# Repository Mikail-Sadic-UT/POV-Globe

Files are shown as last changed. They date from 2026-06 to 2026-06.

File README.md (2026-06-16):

# POV Globe

A persistence-of-vision LED globe. A blade carrying a strip of SK9822 LEDs spins on a brushless motor; image columns are clocked out in sync with the motor's hall sensor so a stable spherical image hangs in mid-air.

---

## How It Works

A hall sensor feeds back the motor's rotation period. A timer divides that period across the number of angular columns and fires at that rate — each tick, the next column of image data is pushed out to the LEDs via DMA while the CPU stays free.

Three display modes:

| Mode | Description |
|---|---|
| Static image | Indexed image loaded from ROM or SD card |
| Animation | GIF streamed from SD card, double-buffered per rotation |
| Mic / VU meter | Electret mic drives a colour bar from hub to tip |

---

## Repository Layout

```
POV-Globe/
├── Firmware/     Code Composer Studio project (TM4C123GH6PM)
├── Hardware/     KiCad 9.0 PCB files
├── Mechanical/   Step files
├── Scripts/      Python image conversion tools
└── BOM.xlsx      Bill of materials
```

---

## Firmware

Targets the TI TM4C123GH6PM (Tiva C) using [Code Composer Studio](https://www.ti.com/tool/CCSTUDIO).

### Quick Start

1. Open the project in Code Composer Studio (`Firmware/src/`).
2. Make sure `main_sd.c` is the active entry point.
3. Connect the board and hit **Debug** — CCS flashes and starts execution.
4. Use the LCD buttons to navigate the menu, select content, and control the motor.

### Adding Content

**ROM image** (compiled into flash, no SD card needed):

```bash
cd Scripts
python globe_convert.py myimage.png
```

Move the output into `Firmware/src/Data/myimage/` and register the entry in `main_sd.c`. See [`Scripts/Documentation.md`](Scripts/Documentation.md) for details.

**SD card animation** (streamed at runtime):

```bash
python globe_convert_gif.py myanim.gif
```

Copy the `.bin` file to the SD card and register the palette entry in `main_sd.c`. See [`Scripts/Documentation.md`](Scripts/Documentation.md) for details.

### Docs

Detailed module documentation lives in `Firmware/src/Documentation/`:

- [`main_sd.md`](Firmware/src/Documentation/main_sd.md) — application architecture, display modes, init order
- [`Motor.md`](Firmware/src/Documentation/Motor.md) — PWM control, hall RPM capture, ramp state machine
- [`SK9822.md`](Firmware/src/Documentation/SK9822.md) — frame builders and wire format
- [`SSI-DMA.md`](Firmware/src/Documentation/SSI-DMA.md) — DMA pipeline and SPI setup

---

## Hardware

KiCad 9.0 is required to open the schematic and PCB files. All design files and documentation are inside the `Hardware/` folder.

---

## Scripts

| Script | Purpose |
|---|---|
| `globe_convert.py` | Converts an equirectangular image to C arrays for ROM or SD use |
| `globe_convert_gif.py` | Converts a GIF to a binary + palette for SD card streaming |
| `toBin.py` | Binary packing utility |

See [`Scripts/Documentation.md`](Scripts/Documentation.md) for full usage.

## Mechanical

See Mechanical Folder for STEP models and assembly. 
Youtube video:

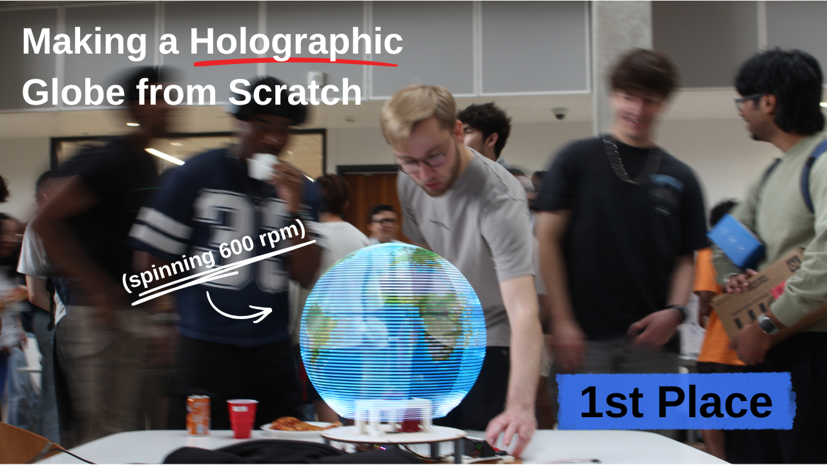
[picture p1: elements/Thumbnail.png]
Demo Video (https://youtu.be/JPuDUcfGZ3w)


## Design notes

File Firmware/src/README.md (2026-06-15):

# POV LED Globe — TM4C123 Driver

A persistence-of-vision LED globe powered by a TM4C123GH6PM. A 143-LED SK9822 strip is mounted on a spinning blade; columns of image data are clocked out at a rate locked to the motor's hall-sensor feedback so a stable image fuses in mid-air.

Supports static images (ROM and SD card), animated GIFs streamed from SD, and a microphone-driven VU meter.

---

## Hardware

| Component | Part | Interface |
|---|---|---|
| MCU | TI TM4C123GH6PM (Tiva C) | 80 MHz |
| LEDs | 143× SK9822 (originally 144) | SSI2 + uDMA, 20 MHz |
| Motor | TEC3650 BLDC + 6:1 gearbox | PWM + hall capture |
| LCD | ST7735 128×160 colour TFT | SSI0 |
| SD card | FAT32 SD/SDHC | SSI0 (shared bus) |
| Microphone | Analog electret | ADC0 / AIN0 |

---

## Pin Map

```
PORT A — LCD + SD card (SSI0)
  PA2  SSI0 SCLK    → ST7735 SCK / SD card SCK
  PA3  SSI0 FSS     → ST7735 CS
  PA4  SSI0 RX      → SD card MISO
  PA5  SSI0 TX      → ST7735 MOSI / SD card MOSI
  PA6  GPIO out     → ST7735 D/C
  PA7  GPIO out     → ST7735 RESET

PORT B — LEDs (SSI2) + LCD buttons
  PB1  GPIO in      → LCD button "Up"
  PB2  GPIO in      → LCD button "Down"
  PB3  GPIO in      → LCD button "Select"
  PB4  SSI2 SCLK    → SK9822 CLK
  PB7  SSI2 TX      → SK9822 DI

PORT C — Motor
  PC4  WT0CCP0      → hall sensor (open-drain, falling edge)
  PC5  M0PWM7       → motor PWM (active-low, 20 kHz)
  PC6  GPIO out     → direction (0 = forward)

PORT E — Microphone
  PE3  AIN0         → mic analog input

PORT F — Motor buttons + RGB heartbeat LED
  PF0  GPIO in      → motor spin-up
  PF1  GPIO out     → red LED
  PF2  GPIO out     → blue LED
  PF3  GPIO out     → green LED
  PF4  GPIO in      → motor spin-down

SD card chip-select: dedicated GPIO (see diskio_DMA.c)
```

---

## Repository Layout

```
.
├── main.c                  Stripped-down version, ROM-only (no SD card)
├── main_sd.c               Full application, the one you'll use
├── main.h
│
├── Drivers/
│   ├── inc/                Driver headers
│   └── src/                Driver source
│       ├── SK9822.c              Frame builders (image → SPI bytes)
│       ├── SK9822_DMA_SSI.c      DMA pipeline (SPI bytes → LEDs)
│       ├── Motor.c               PWM + hall RPM + ramp state machine
│       ├── LCD.c                 ST7735 menu UI
│       ├── GPIO.c                Port B/F button ISRs + heartbeat LED
│       ├── Mic.c                 ADC0 single-sample reader
│       ├── DMA_Common.c          uDMA controller init
│       ├── SD_DMA.c              SD card SPI-RX via uDMA
│       ├── diskio_DMA.c          FatFs disk I/O backend
│       ├── ff.c                  FatFs filesystem (3rd party)
│       ├── ST7735.c              LCD low-level driver (3rd party)
│       ├── Timer*A.c             32-bit periodic timer wrappers
│       └── Unified_Port_Init.c   GPIO bring-up boilerplate
│
├── Data/                   Image and animation data
│   ├── map_*.{c,h}              Earth (ROM, 8-bit)
│   ├── dermot/, vote/, eye/     Other ROM 8-bit images
│   ├── cat_space/, frog/, ...   Animation palettes (data on SD as .bin)
│   └── globe_old/               Legacy 144-LED data, kept for reference
│
├── Tests/                  Standalone test programs
│   ├── DMA_test.c               Exercise SK9822 DMA pipeline alone
│   ├── Motor_test.c             Sweep motor 0%-100% in both directions
│   ├── SD_Card.c                SD card read smoke test
│   ├── SD_Card_Sanity_Check.c   FatFs read/write verification
│   └── SD_Card_Write.c          (unused) write image data to SD
│
├── Documentation/          Module-level docs
│   ├── SSI-DMA.md               LED DMA pipeline deep-dive
│   ├── SK9822.md                Frame builder reference
│   ├── Motor.md                 Motor driver internals
│   └── main_sd.md               Application architecture
│
└── Debug/                  Build artefacts (gitignored)
```

---

## Quick Start

1. Open the project in **Code Composer Studio**.
2. Make sure the build is targeting `main_sd.c` (not `main.c` or any of the test programs — only one `main` can be active at a time).
3. Connect the board, hit **Debug**. CCS auto-flashes and starts execution.
4. The LCD shows the menu. Use PB1/PB2/PB3 to navigate.
5. PF0 spins the motor up, PF4 spins it down (also accessible from the LCD menu).

### Switching what gets built

Each `main*.c` defines a different `main()` entry point. To change which one runs, edit the file you don't want to use so its entry point is named something other than `main` (e.g. `main2`, `main88`). Only the file containing the actual `main` will be the program entry.

---

## How It Works

The motor spins a blade carrying a strip of LEDs. A hall sensor tells us the rotation period. We divide that period by the number of angular columns we want, and use that as the firing rate for the hardware Timer. Each Timer tick, the next column of pre-computed image data is expanded to the SPI wire format and shifted out via **DMA + SSI2** — fast enough that the LEDs change colour many times per revolution, painting an image in space. The CPU is mostly idle during all this, free to handle the LCD menu, motor ramp, and SD card streaming.

For a thorough walkthrough see [Documentation/main_sd.md](Documentation/main_sd.md).

---

## Adding New Content

### New ROM image (compiled into flash)

```
python globe_convert.py myimage.png --mode 8bit
mkdir Data/myimage
mv myimage_data.{c,h} myimage_palette.{c,h}  Data/myimage/
```

Then in `main_sd.c`:

```c
#include "Data/myimage/myimage_data.h"
#include "Data/myimage/myimage_palette.h"

static const ContentEntry_t pictures[] = {
    /* ...existing entries... */
    { "MyImage", CONTENT_ROM_8BIT, myimage_data, myimage_palette,
      GLOBE_NUM_COLUMNS, NULL },
};
```

### New animation (streamed from SD)

```
python globe_convert_gif.py myanim.gif --mode 4bit
cp myanim.bin /path/to/sd/  →  rename to 8.3 format, e.g. mya.bin
mkdir Data/myanim
mv myanim_palette.{c,h}  Data/myanim/
```

Then in `main_sd.c`:

```c
#include "Data/myanim/myanim_palette.h"

static const ContentEntry_t animations[] = {
    /* ...existing entries... */
    { "MyAnim", CONTENT_SD_4BIT_ANIM, NULL, myanim_palette, 0, "mya.bin" },
};
```

The data file goes on the SD card; the palette is small enough to live in flash.

---

## Compile-Time Toggles

In `main_sd.c`:

| Macro | Default | Effect |
|---|---|---|
| `HALL_SYNC` / `FIXED_TIMER` | `HALL_SYNC` | Column rate locked to motor RPM, or fixed at `FIXED_PERIOD` |
| `ISR_BUILD_ON_DMA_DONE` / `ISR_BUILD_IN_TIMER` | `ISR_BUILD_ON_DMA_DONE` | Where `BuildFrame()` runs |
| `FIXED_PERIOD` | `152000` | Initial / fallback Timer4A reload (80 MHz ticks) |
| `brightness` | `16` | Global LED brightness 0–31 (variable, not macro) |

In `Drivers/inc/Motor.h`:

| Macro | Default | Effect |
|---|---|---|
| `MOTOR_SETPOINT` | `67` | Default duty% the spin-up button targets |
| `MIN_STARTSPEED` | `20` | Minimum duty% needed to overcome friction |
| `MAX_SPEED` | `90` | Hard ceiling for `Motor_SetSpeed()` |
| `MOTOR_SPINUP_MS` | `250` | ms per 1% step on spin-up |
| `MOTOR_SPINDOWN_MS` | `100` | ms per 1% step on spin-down |

---

## Interrupt Priority Map

| IRQ | Source | Priority | Notes |
|-----|---|---|---|
| 94  | Wide Timer 0A (hall) | **1** | missed edge = wrong RPM = drift|
| 57  | SSI2 (LED DMA done) | 2 | Triggers next frame build |
| — | SysTick (1 ms) | 2 | Motor ramp, stall check |
| 70  | Timer4A (column clock) | 3 | Fires `LEEEED()` |
| 92  | Timer5A (FatFs disk timer) | 4 | SD card timeouts |
| 1 | Port B (LCD buttons) | 5 | Human input |
| 30  | Port F (motor buttons) | 5 | Human input |

---

## Memory Footprint

```
SRAM (32 KB total):
  sdMem (image union)              ~20 KB
  DMA_FRAME + BUF_FRAME             1.2 KB
  stack, ISR vars, FatFs state    ~ 1.5 KB
  free                            ~ 9 KB

Flash:
  application code                  ~25 KB
  ROM image data                    ~20 KB per 8-bit image
  ROM palette data                   768 B per 8-bit, 48 B per 4-bit
  FatFs                             ~10 KB
```

ROM image data dominates flash usage. Each additional 8-bit image adds 140 × 143 = 20,020 bytes.

---

## Documentation

For deeper dives into specific subsystems:

- [Documentation/main_sd.md](Documentation/main_sd.md) — application architecture, mode switching, content table, init order
- [Documentation/Motor.md](Documentation/Motor.md) — PWM control, hall capture ISR, RPM math, ramp state machine
- [Documentation/SK9822.md](Documentation/SK9822.md) — frame builders, wire format, compressed formats
- [Documentation/SSI-DMA.md](Documentation/SSI-DMA.md) — LED DMA pipeline, ping-pong descriptors, SSI2 init

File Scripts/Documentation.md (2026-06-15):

# globe_convert.py

Converts an equirectangular image into C arrays ready for use on the TM4C123 POV globe driver.

---

## Usage

```bash
python globe_convert.py <image>
```

**Example:**
```bash
python globe_convert.py world_map.png
```

All tuning parameters are configured inside the script — no command-line flags needed.

---

## Configuration

Edit the `CONFIG` block at the top of the script before running:

```python
NUM_COLUMNS   = 140     # Angular slices per 180° blade sweep <-- Should be theoretical limit
NUM_LEDS      = 144     # Total LEDs on the blade
FRONT_LEDS    = 72      # LEDs on the front face
PALETTE_SIZE  = 256     # Colours in the 8-bit palette (max 256)
OUTPUT_DIR    = "."     # Directory to write generated files into
```

| Parameter | Description |
|---|---|
| `NUM_COLUMNS` | Angular resolution — number of image slices per half rotation. 140 gives ~1.28° per step at 900 RPM. |
| `NUM_LEDS` | Total LEDs on the blade. Must match `NUM_LEDS` in `SK9822.h`. |
| `FRONT_LEDS` | How many LEDs are on the front face. Remaining LEDs are the back face. |
| `PALETTE_SIZE` | Number of colours in the palette. 256 = 8-bit. Reducing to 16 enables 4-bit mode. |
| `OUTPUT_DIR` | Where the four output files are written. Created if it doesn't exist. |

---

## Input Image

The script for now expects an **equirectangular projection** image (but will work with whatever):

- **X axis** → angular position (0–360°, left to right)
- **Y axis** → radial position (hub at top, tip at bottom)

The image is automatically resized to `(NUM_COLUMNS × 2) × NUM_LEDS` pixels internally, so any input resolution works.

Standard equirectangular images (world maps, 360° photos) work directly. If the image is not equirectangular it will produce distorted output. Will probably have to make another script to do this, or figure something out for general photos.

---

## Globe Geometry

The blade has 144 LEDs arranged radially from hub to tip:

```
Hub                                       Tip                                      Hub
 |-------- Front face (LED 0–71) ----------|-------- Back face (LED 72–143) --------|
```

- **Front face** (LED 0–71): sampled hub→tip from the column angle
- **Back face** (LED 72–143): sampled tip→hub from column angle + 180°, stored in reverse radial order so LED 72 sits at the tip adjacent to LED 71

This means the image is seamless across the physical blade centre — the pixel at LED 71 (front tip) and LED 72 (back tip) are adjacent in the source image.

A full rotation is reconstructed from two blade passes:

```
Pass 1 (0°–180°):   columns 0–139   →  front face = 0°–180°,  back face = 180°–360°
Pass 2 (180°–360°): same columns    →  front face = 180°–360°, back face = 0°–180°
```

---

## Processing Pipeline

```
Load image
    │
    ▼
Resize to (NUM_COLUMNS×2) × NUM_LEDS
    │
    ▼
K-means clustering (256 colours)  ←  builds optimal palette for this image
    │
    ▼
Quantize pixels → palette indices
    │
    ▼
Sample globe columns
    │   for each column: sample front strip at angle,
    │                    sample back strip at angle + 180°
    ▼
Write C files
```

### Palette generation

The palette is built using **MiniBatchKMeans clustering** — it finds the 256 colours that best represent the full colour distribution of the image. This is strictly better than a fixed 3-3-2 mapping because the 256 entries are chosen specifically for your image rather than being uniformly distributed.

### Quantization

Each pixel is mapped to its nearest palette entry using squared Euclidean distance in RGB space. Processed in chunks of 4096 pixels to avoid memory issues on large images.

---

## Output Files

Four files are generated in `OUTPUT_DIR`:

| File | Contents | Size |
|---|---|---|
| `palette.h` | `extern` declaration, `PALETTE_SIZE` define | — |
| `palette.c` | `const uint8_t palette[256][3]` — RGB entries | 768 bytes |
| `globe_data.h` | `extern` declaration, `GLOBE_NUM_COLUMNS` / `GLOBE_NUM_LEDS` defines | — |
| `globe_data.c` | `const uint8_t globe[140][144]` — palette indices | 20,160 bytes |

**Total: ~20,928 bytes (~20.4 KB)** — fits in TM4C123 32 KB SRAM with ~11.6 KB spare.

> Set as `const` to place them in flash (256 KB) instead of SRAM, freeing SRAM for frame buffers and stack.

---

## MCU Integration

Add the four generated files to your project under `Data/`:

```
Data/
  palette.h
  palette.c
  globe_data.h
  globe_data.c
```

Include in your main file and call `BuildFrame_8bit` with the current column:

```c
#include "../Data/globe_data.h"
#include "../Data/palette.h"

uint16_t col        = 0;
uint8_t  brightness = 2;   // 0-31

// In main loop:
if(framePending){
    BuildFrame_8bit(BUFF, globe[col], palette, brightness);
    col = (col + 1) % GLOBE_NUM_COLUMNS;
    frameDirty  = 1;
    framePending = 0;
}
```

`BuildFrame_8bit` expands the 144 palette indices for column `col` into the full 596-byte SK9822 wire format (start frame + BGR LED frames + end frame) and writes it into `BUFF`.

---

## Dependencies

```bash
pip install pillow numpy scikit-learn
```

| Package | Use |
|---|---|
| `Pillow` | Image loading and resizing |
| `numpy` | Array operations and vectorised quantization |
| `scikit-learn` | `MiniBatchKMeans` for palette generation |

---

## Notes

- **One palette per image** — the palette is optimised for the specific input image. If you load multiple images on the globe, each needs its own palette, or you can generate a shared palette by running k-means across all images combined.
- **Equirectangular only** — other projections (Mercator, stereographic, etc.) will produce distorted output without a pre-conversion step.
- **Brightness** — the `brightness` parameter (0–31) is the SK9822 global brightness field, separate from pixel colour values. Stay low (1–3) because this shit is bright af.

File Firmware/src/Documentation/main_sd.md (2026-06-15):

# main_sd.c — POV Globe Application

## Overview

The application layer for the POV LED globe. Coordinates four subsystems:

- **Frame builders** ([SK9822.md](SK9822.md)) — turn images into SPI byte streams
- **DMA driver** ([SSI-DMA.md](SSI-DMA.md)) — shifts frames out to the LEDs
- **Motor driver** ([Motor.md](Motor.md)) — keeps the blade spinning, provides hall feedback
- **LCD menu** — user input for mode/content selection

```
┌─────────────────┐
│  LCD menu       │ ── selects ───▶ Globe_ToggleMode / Globe_ChangeContent
│  (LCD.c)        │
└─────────────────┘
                                            │
                                            ▼
┌─────────────────┐         ┌────────────────────────────────┐
│  Motor (hall)   │ ──RPM──>│  Timer4A ISR  (HALL_SYNC mode) │
└─────────────────┘         │     ↓                          │
                            │  LEEEED() ──> LoadDMA()        │
                            │                  ↓             │
                            │   SSI2_Handler ──> BuildFrame()│
                            │     (DMA done)                 │
                            └────────────────────────────────┘
                                            │
                                            ▼
                            ┌────────────────────────────────┐
                            │  Mic / SD / ROM / palette LUT  │
                            └────────────────────────────────┘
```

---

## Display Modes

```c
typedef enum {
    MODE_8BIT_STATIC,   // single 8-bit image, ROM or SD
    MODE_4BIT_ANIM,     // 4-bit animation from SD, double-buffered
    MODE_MIC            // VU meter from PE3 ADC
} DisplayMode_t;
```

Three sources of image data feed the same DMA pipeline:

| Mode | Data source | Per-column behaviour |
|---|---|---|
| `MODE_8BIT_STATIC` + `SRC_ROM` | flash array (`romData[col]`) | palette lookup |
| `MODE_8BIT_STATIC` + `SRC_SD`  | RAM (`sdMem.static8[col]`) | palette lookup |
| `MODE_4BIT_ANIM` | RAM (`sdActive[col]`) | palette lookup, swap buffers at col=0 |
| `MODE_MIC` | ADC sample | `BuildFrame_VU()` |

---

## Memory Budget

The TM4C123 has 32 KB of SRAM. The largest user is the SD/animation buffer pool, which uses a **union** to overlay 8-bit and 4-bit layouts on the same memory:

```c
static union {
    uint8_t static8[140][143];          // 20,020 B — 8-bit static
    struct {
        uint8_t a[140][72];             // 10,080 B — 4-bit buffer A
        uint8_t b[140][72];             // 10,080 B — 4-bit buffer B
    } anim4;
} sdMem;                                // 20,160 B total
```

In addition:

```
DMA_FRAME, BUF_FRAME (double SPI buffer)  =  2 × 592   = 1,184 B
sdMem (union)                             ≈            = 20,160 B
ROM image data (in flash, not SRAM)
Misc state                                ≈            = ~500 B
                                                         ───────
                                                        ~22 KB used
```

Adding more pictures or animations costs **flash** (palette + index data),
not SRAM, since `pictures[]` and `animations[]` are `const`.

---

## Double-Buffering Strategy

Two layers of double-buffering, used at different time scales:

### 1. SPI wire buffers (per column)

```
LIVE  →  being shifted out by DMA
BUFF  →  being filled by BuildFrame_xxx()

After DMA completes:
   swap(LIVE, BUFF)
   restart DMA on new LIVE
   build next column into new BUFF
```

This is what `LoadDMA()` does — it checks `dmaBusy`, swaps pointers if a new column is ready (`frameDirty`), and kicks the next transfer.

### 2. Animation frame buffers (per rotation)

```
sdActive  →  140 columns being read by BuildFrame_4bit
sdLoading →  next animation frame, loaded from SD in main loop

When col == 0 (rotation boundary) and sdReady:
   swap(sdActive, sdLoading)
   sdReady = 0
```

The swap only happens at the rotation boundary so the user never sees a torn frame mid-rotation. The main loop watches `sdReady` and starts loading the next frame as soon as the previous one is consumed.

---

## ISR Architecture

Two compile-time options control where work happens (see toggles in main_sd.c):

### `ISR_BUILD_IN_TIMER`
Both `LoadDMA()` and `BuildFrame()` run in the Timer4A ISR.

```
Timer4A tick:
   ├── HallSync_UpdatePeriod()    // ~3 µs
   ├── LoadDMA()                  // ~2 µs
   └── BuildFrame()               // ~10 µs
                                  total ~15 µs ISR
```

Simple. Fine up to ~50 kHz column rate.

### `ISR_BUILD_ON_DMA_DONE`  (current default)

Timer4A only kicks DMA. Frame building runs from `SSI2_Handler` after the SPI transfer completes.

```
Timer4A tick:                    SSI2 DMA-done (~30 µs after timer):
   ├── HallSync_UpdatePeriod()      └── DMA_Done_Callback()
   └── LoadDMA()                          └── BuildFrame()
       (~5 µs ISR)                              (~10 µs ISR)
```

CPU isn't blocked during the SPI transfer — `BuildFrame()` runs in parallel with SPI shifting. Better for high column rates.

`DMA_Done_Callback()` is called from `SSI2_Handler` (in SK9822_DMA_SSI.c).

---

## Timing: Fixed vs Hall-Sync

```
#define HALL_SYNC      // (current default)
// #define FIXED_TIMER
```

### `FIXED_TIMER`
Timer4A fires at a constant period (`FIXED_PERIOD = 152000` ticks at 80 MHz, ≈526 Hz). Image position drifts as motor RPM varies. (Only as accurate as what you are reading directly from the motor, and slipage down the line will cause image drift)

### `HALL_SYNC`
Every Timer4A tick, the period is recomputed from the most recent measured motor revolution:

```
colPeriod = revPeriod × MOTOR_GEAR_RATIO / SD_NUM_COLUMNS
          = revPeriod × 6 / 140
```

Image stays locked to physical position even if motor RPM drifts. Until the first revolution is measured, falls back to `FIXED_PERIOD`.

The clamps `5000 ≤ colPeriod ≤ 400000` bound the column rate to roughly **200 Hz – 16 kHz**, avoids silly values and nothing happening when motor off.

---

## Content Table

`pictures[]` and `animations[]` register all selectable content. Each entry is a `ContentEntry_t`:

```c
typedef struct {
    const char       *name;
    ContentType_t     type;          // ROM_8BIT / SD_8BIT / SD_4BIT_ANIM
    const uint8_t   (*romData)[NUM_LEDS];
    const uint8_t   (*palette)[3];
    uint16_t          romCols;
    const char       *sdFilename;
} ContentEntry_t;
```

### Adding new content

**ROM-resident image** (compiled into flash, no SD card needed):

1. Run `globe_convert.py` on your image
2. Copy the generated `*_data.h/c` and `*_palette.h/c` into `Data/myImage/`
3. `#include` the headers in main_sd.c
4. Add an entry to `pictures[]`:
   ```c
   { "MyImage", CONTENT_ROM_8BIT, my_data, my_palette, GLOBE_NUM_COLUMNS, NULL },
   ```

**SD card animation** (4-bit GIF, no flash cost):

1. Convert the GIF: `python globe_convert_gif.py myAnim.gif --mode 4bit`
2. Copy the resulting `myAnim.bin` to the SD card
3. `#include` the palette header (palette still goes in flash)
4. Add an entry to `animations[]`:
   ```c
   { "MyAnim", CONTENT_SD_4BIT_ANIM, NULL, my_palette, 0, "mya.bin" },
   ```

The SD filename is limited to 8.3 characters by FatFs in default config.

---

## LCD Menu Integration

The LED menu in `LCD.c` calls into main_sd.c through two extern functions:

```c
void Globe_ToggleMode(void);    // cycles picture → animation → mic → picture
void Globe_ChangeContent(void); // cycles within current category
```

`ledModeAnim` is shared between the two files (defined in LCD.c, read here):

| Value | Meaning |
|---|---|
| 0 | Picture mode |
| 1 | Animation mode |
| 2 | Mic mode |

LCD.c handles the button input and screen rendering. main_sd.c handles the actual mode switching and content loading.

---

## Mic Mode Detail

```c
if (displayMode == MODE_MIC) {
    raw = Mic_Read();
    uint16_t level = ((raw * FRONT_LEDS) / 4096) - 33;
    BuildFrame_VU(BUFF, level, brightness);
}
```

`Mic_Read()` triggers ADC0 sequencer 3 (single sample on PE3/AIN0) and polls for completion. Returns 0–4095.

Scaling to LED count:
```
level = raw × 71 / 4096 - 33
```

The `-33` offset trims out ambient ADC bias so the bar sits near zero in silence. Tune per microphone.

`BuildFrame_VU()` ([SK9822.md](SK9822.md)) draws a green→yellow→red bar from hub to tip on both faces.

The mic is sampled once per column (~500 Hz with default timing). The current code shows the *instantaneous* sample.

---

## Initialisation Sequence

`INITIALIZE()` brings up subsystems in dependency order:

```
1. PLL_Init(80MHz)               clock first — everything else needs it
2. SK9822_20MHZ()                SSI2 + GPIO PB4/PB7
3. DMA_Init()                    uDMA controller
4. SK9822_DMA_CH13_Init()        LED DMA channel
5. SD_DMA_CH10_Init()            SD card DMA channel
6. Motor_Init()                  PWM + hall capture
7. Motor_Stop()                  ensure motor is off
8. PF_Init() / PB_Init()         button GPIO + IRQs
9. SysTick_Init(1ms)             tick + ramp + stall check
10. Mic_Init()                   ADC0 seq3
11. BuildFrame_Solid(LIVE/BUFF)  clear LED buffers
12. LCD_Menu_Init()              ST7735 + initial render
```

`Timer4A_Init()` is called from `main()` after `SetMode_ROM()` loads the first picture, so the ISR doesn't fire on uninitialised data.

---

## Main Loop

```c
while (1) {
    if (displayMode == MODE_4BIT_ANIM && !sdReady)
        SD_LoadNextFrame();          // SD I/O happens here, not in ISR

    buttonHandler();                  // consume LCD button flags

    if (motor_state_changed) {
        // redraw motor status indicator on LCD
    }
}
```

All slow / blocking operations (SD card reads, LCD redraws) happen here so the ISRs stay short.

---

## Compile-time Toggles Summary

| Toggle | Default | Effect |
|---|---|---|
| `HALL_SYNC` / `FIXED_TIMER` | `HALL_SYNC` | Column rate locked to motor or fixed |
| `ISR_BUILD_ON_DMA_DONE` / `ISR_BUILD_IN_TIMER` | `ISR_BUILD_ON_DMA_DONE` | Where BuildFrame runs |
| `FIXED_PERIOD` | `152000` | Initial / fallback Timer4A period |
| `brightness` (variable) | `16` | Global LED brightness, 0–31 |

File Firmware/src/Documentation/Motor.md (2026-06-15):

# BL2430 Motor Driver

## Overview

Drives a TEC3650 brushless DC motor through a 6:1 reduction gearbox.
Provides three things:

1. **PWM speed control** with non-blocking spin-up / spin-down ramps
2. **Direction control** via a digital pin
3. **Live RPM measurement** from the hall-effect sensor

The motor sits on Port C:

| Pin | Function | Direction | Notes |
|-----|---|---|---|
| PC4 | WT0CCP0  | input  | Hall sensor, falling-edge capture |
| PC5 | M0PWM7 | output | Active-low PWM, 20 kHz |
| PC6 | GPIO | output | Direction (0 = forward) |

---

## PWM Speed Control

PWM uses **PWM Module 0, Generator 3, output B** (M0PWM7 on PC5). The signal is **active-low**: the line idles high (motor off) and pulses low for the active fraction of each period.

```
Period = 80 MHz / 20 kHz = 4000 counts
Duty   = CMPB / LOAD
```

Three special cases short-circuit the normal counter:
- **0%** → GENB forced constant high (motor off)
- **100%** → GENB forced constant low (full speed)
- **1–99%** → normal count-down PWM

### Rate Limiter

`Motor_SetSpeed()` rejects single-call jumps larger than `MAX_STEP` (25%). This protects the driver and motor from sudden current spikes. To change speed by more than 25%, use `Motor_Spinup()` / `Motor_Spindown()` which ramp gradually.

---

## Spin-Up / Spin-Down Ramps

Both functions are **non-blocking** — they store the target state and return. `Motor_Tick()` (called from SysTick at 1 ms) advances the ramp by one step every `motorStepDelay` ms.

```
MOTOR_IDLE
    │
    │  Motor_Spinup(250, 67)
    ▼
MOTOR_SPINNING_UP  ──── increment 1%/250ms ──── reaches target ──▶ MOTOR_IDLE
    │
    │  Motor_Spindown(100)  [preempts spinup]
    ▼
MOTOR_SPINNING_DOWN ── decrement 1%/100ms ──── reaches 5% ──▶ Motor_Stop() ──▶ MOTOR_IDLE
```

Spin-down always preempts spin-up. Spin-up is ignored if a spin-down is already running.

The spin-down ramp stops at 5% rather than 0% and calls `Motor_Stop()` directly — at very low duty cycles the motor behaviour is unpredictable, so it's safer to cut PWM cleanly than to creep down to zero.

### State variables (all volatile)

| Variable | Owner | Purpose |
|---|---|---|
| `motorRampState` | Motor_Tick / Spinup / Spindown | Current ramp phase |
| `motorCurSpeed` | Motor_Tick | Most recently applied duty% |
| `motorTargetSpeed` | Motor_Spinup | Spin-up destination |
| `motorStepDelay` | Spinup / Spindown | ms between 1% steps |
| `motorLastTick` | Motor_Tick | msTick when last step ran |
| `motor_state_changed` | all writers | Flag for main loop to redraw LCD |

---

## Hall Sensor RPM Capture

PC4 receives the hall sensor's open-drain output. We use **Wide Timer 0A in capture mode** — every falling edge latches the timer's current value, generating an interrupt.

The TEC3650 produces **12 hall pulses per motor revolution** (4 pole pairs × 3 phases). One full motor revolution = 12 captured edges.

### ISR Flow (`WideTimer0A_Handler`)

```
edge fires
    │
    ▼
read WTIMER0_TAR_R (latched timestamp)
    │
    ▼
delta = wtPrev - now    (timer counts down from 0xFFFFFFFF)
    │
    ▼
glitch reject: delta < 0.6 × lastValidDelta?  ──▶ ignore
    │
    ▼
stall check: delta > STALL_DELTA (1 sec)?     ──▶ motorRPM = 0, reset
    │
    ▼
update gearPulseCount (mod GEAR_PPR=54)
accumulate wtDeltaSum, increment wtPulse
    │
    ▼
wtPulse == 12?                                ──▶ compute motorRPM,
                                                  save lastRevPeriod,
                                                  reset accumulator
```

### RPM Math

```
RPM = (SYS_CLK × 60) / (HALL_PPR × delta_per_pulse)
    = RPM_SCALE_REV / wtDeltaSum

where RPM_SCALE_REV = 80,000,000 × 60 = 4,800,000,000
and wtDeltaSum = sum of 12 inter-pulse intervals (one full rev)
```

Computing once per revolution rather than per pulse averages out timing jitter and avoids divisions on every interrupt.

### Glitch Rejection

The hall sensor is open-drain with a pull-up. Without a series resistor on the line, fast slew rates can produce double-pulses near the threshold. The ISR rejects any delta less than 60% of the last valid interval, which discards these glitches without affecting legitimate speed changes (motor accel/decel happens on a much slower timescale).

### Stall Detection

`Motor_StallCheck()` is called from SysTick every 1 ms. It reads the **live** timer value (`WTIMER0_TAV_R`) — not the latched capture register — to measure time since the last edge. If more than 1 second has passed, it forces RPM to 0 and resets the capture state. This handles the case where the motor stops without producing a final edge.

---

## Hall-Sync API (for POV column timing)

The POV globe needs columns delivered at a rate that matches the physical rotation. Two getters expose the hall capture state to `main_sd.c`:

| Function | Returns |
|---|---|
| `Motor_GetRevPeriod()` | 80 MHz tick count for one full motor revolution. 0 = no measurement yet. |
| `Motor_GetGearPulseCount()` | Current position within one gear rev, [0, 54). |
| `Motor_GetGearAngle()` | Same, but in degrees [0, 360). |

In `main_sd.c`, `HallSync_UpdatePeriod()` reads `Motor_GetRevPeriod()` and computes the column timer period:

```
colPeriod = revPeriod × MOTOR_GEAR_RATIO / SD_NUM_COLUMNS
          = revPeriod × 6 / 140
```

This locks the column rate to actual motor speed — the image stays stable even if RPM drifts. (Only factoring Motor drift, any mechanical drifting down the line, ie gear/belt slippage will not be caught)

---

## Public API Summary

```c
void     Motor_Init(void);
uint8_t  Motor_SetSpeed(int8_t percent);     // rate-limited
uint8_t  Motor_SetDirection(uint8_t dir);    // only when stopped
uint8_t  Motor_Stop(void);
void     Motor_Spinup(uint32_t msPerStep, uint8_t targetDuty);
void     Motor_Spindown(uint32_t msPerStep);
void     Motor_Tick(void);                   // call from SysTick
void     Motor_StallCheck(void);             // call from SysTick

uint32_t Motor_GetRPM(void);                 // motor RPM
uint32_t Motor_GetGearRPM(void);             // = motorRPM / 6
uint8_t  Motor_GetDuty(void);                // current duty %

uint32_t Motor_GetRevPeriod(void);           // for hall-sync
uint8_t  Motor_GetGearPulseCount(void);
uint16_t Motor_GetGearAngle(void);
```

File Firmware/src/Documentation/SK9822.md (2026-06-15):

# SK9822 Frame Builders

## Overview

`SK9822.c` provides functions that **build complete SPI frames** in the SK9822 wire format. The DMA driver (`SK9822_DMA_SSI.c`) shifts these frames out — see [SSI-DMA.md](SSI-DMA.md) for that side.

Every builder writes the same buffer layout:

```
┌─────────────┬───────────────────────────┬─────────────┐
│ START_BYTES │  NUM_LEDS × 4 bytes       │  END_BYTES  │
│  4 × 0x00   │  per LED:                 │  16 × 0xFF  │
│             │  [global][B][G][R]        │             │
└─────────────┴───────────────────────────┴─────────────┘
```

Total `FRAMESIZE` = **592 bytes** (4 + 143×4 + 16, supposed to be 144 but one led broke).

---

## SK9822 Wire Format

### Per-LED frame (4 bytes)

```
byte 0:  111 b b b b b     (top 3 bits = 0xE0, bottom 5 = brightness 0-31)
byte 1:  blue
byte 2:  green
byte 3:  red
```

The "global" brightness field is a 5-bit current scaler applied by the LED controller before its 8-bit PWM. Setting global = 0 turns the LED off without sending all-zero RGB, which is a useful distinction when chaining frames.

`START_BITS = 0xE0` is OR'd with the 5-bit brightness to produce the global byte. The driver passes `0xE0` (i.e. global = 0) as the global value for "off" pixels, and `START_BITS | brightness` for lit pixels.

### Wire order

The SK9822 datasheet specifies **BGR order** for the colour bytes, even though every builder accepts RGB inputs. The `WRITE_LED` macro reorders them on output:

```c
#define WRITE_LED(frame, idx, global, r, g, b) \
    do { (frame)[(idx)++] = (global);          \
         (frame)[(idx)++] = (b);               \
         (frame)[(idx)++] = (g);               \
         (frame)[(idx)++] = (r); } while(0)
```

Callers always pass natural `(r, g, b)`. The macro is the single point that knows about the wire order.

### Start and End

The 4-byte all-zero start is a synchronization marker — the SK9822 sees four 0x00 bytes and resets its internal frame state machine.

The end frame is `ceil(NUM_LEDS / 2)` bytes of **0xFF**. Its purpose is to keep the SPI clock running long enough for the last LED's data to propagate through the daisy chain. 16 bytes is enough in practice — the LEDs latch on idle clock, not on a specific bit pattern.

---

## Strip Geometry (POV Globe)

The blade has 143 active LEDs split between two faces:

```
Front face: LED 0  → LED 70  (71 LEDs, hub → tip)
Back  face: LED 71 → LED 142 (72 LEDs, tip → hub)
              ▲              ▲
              │              └ LED 142 = back hub, forced black
              └ LED 71 sits adjacent to LED 70 at the tip

Active LEDs per face = 71 (symmetric image across blade centre)
```

The chain length (`NUM_LEDS = 143`) is one short of the original 144 — the hub LED on the front face was physically removed and the back hub is forced black to keep the image symmetric.

```c
#define NUM_LEDS    143
#define FRONT_LEDS   71
```

---

## Compressed Format Builders

Different image data formats trade memory for colour fidelity. Every builder expands one column of compressed data into a full 592-byte frame.

| Builder | Bytes/LED | Colours | Per-column bytes | Use case |
|---|---|---|---|---|
| `BuildFrame_1bit` | 1/8 | 2 + brightness LUT | 18 | Long animations, maximum compression |
| `BuildFrame_4bit` | 1/2 | 16 chosen | 72 | Animated GIFs (current default) |
| `BuildFrame_332`  | 1 | 256 fixed (RRRGGGBB) | 143 | Quick conversions, no palette generation |
| `BuildFrame_8bit` | 1 | 256 chosen | 143 | Static images (current default) |
| `BuildFrame_565`  | 2 | 65,536 | 286 | Highest quality, doesn't fit in SRAM for animation |

### 4-bit packing

Two LEDs per byte: high nibble = even index, low nibble = odd index. Since `NUM_LEDS` is odd, the last byte's low nibble is unused.

```c
uint8_t entry = (i & 1) ? (col4bit[i >> 1] & 0x0F) : (col4bit[i >> 1] >> 4);
```

### 8-bit palette

Direct array index into a `[256][3]` RGB palette. This is the simplest mapping and is what `BuildFrame_8bit` uses. The palette lives in flash; only the index column changes per frame.

### 565 / 332 expansion

```c
expand565(c, r, g, b)  /* RRRRRGGGGGGBBBBB → 8-bit channels */
expand332(c, r, g, b)  /* RRRGGGBB         → 8-bit channels */
```

These are bit-shift only — no palette lookup. Useful when you want to skip palette generation entirely or store data in a generic raster format.

---

## Special Builders

### `BuildFrame_Solid` — uniform colour

Used to clear frames at startup. Calls `NormalizeRGB()` first to scale the channels proportionally if `r + g + b > 255`. This preserves hue when the LEDs would otherwise clip to white.

### `BuildFrame_Pixel` — single LED

Lights one LED at position `pos`, leaves all others off (with global = 0xE0 = brightness 0). Used for hardware testing and bring-up.

### `BuildFrame_VU` — microphone VU meter

Lights LEDs from hub to tip on both faces, proportional to a level value [0, FRONT_LEDS]:

```
hub                                         tip
 ●─●─●─●─●─●─●─●─●─●─○─○─○─○─○─○─○─○─○─○─○      level = 10
green ────────────────► yellow ────► red
```

Both faces show the same bar height. The colour gradient spans hub→tip:

```c
uint8_t frac = (uint8_t)((uint32_t)i * 255 / FRONT_LEDS);
WRITE_LED(frame, idx, global, frac, 255 - frac, 0);
//  i = 0  → frac = 0   → (R=0,   G=255, B=0) green
//  i = 35 → frac = 125 → (R=125, G=130, B=0) yellow
//  i = 70 → frac = 251 → (R=251, G=4,   B=0) red
```

The back hub LED is always forced off to keep the image symmetric across the blade centre.

---

## Brightness Handling

There are **two** brightness controls:

1. **Per-LED 5-bit global** — the high 5 bits of the global byte, applied by the LED controller as a current limiter. Range 0–31.
2. **RGB values themselves** — the 8-bit PWM duty cycle for each channel.

The builders write both: `(global & 0x1F) | START_BITS` for the global byte, and the raw RGB values for the colour bytes. Most callers leave the global at a fixed value (e.g. 16) and modulate via the palette colours.

`NormalizeRGB()` only runs in `BuildFrame_Solid` and `BuildFrame_Pixel` because their callers might pass uncontrolled RGB values. Palette-based builders skip it because palettes are already designed with reasonable brightness levels.

---

## Public API

```c
void BuildFrame_Solid(uint8_t *frame, uint8_t r, g, b, brightness);
void BuildFrame_Pixel(uint8_t *frame, uint16_t pos, uint8_t r, g, b, brightness);

void BuildFrame_565 (uint8_t *frame, const uint16_t *col565,  uint8_t brightness);
void BuildFrame_332 (uint8_t *frame, const uint8_t  *col332,  uint8_t brightness);
void BuildFrame_1bit(uint8_t *frame, const uint8_t  *col1bit, uint8_t brightness);
void BuildFrame_4bit(uint8_t *frame, const uint8_t  *col4bit,
                     const uint8_t palette[16][3], uint8_t brightness);
void BuildFrame_8bit(uint8_t *frame, const uint8_t  *col8bit,
                     const uint8_t palette[256][3], uint8_t brightness);

void BuildFrame_VU  (uint8_t *frame, uint16_t level, uint8_t brightness);
```

All functions write exactly `FRAMESIZE` (592) bytes into `frame[]`.

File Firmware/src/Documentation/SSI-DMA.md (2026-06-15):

# SK9822 DMA/SSI Driver

## Hardware Path: CPU → uDMA → SSI2 → LEDs

```
SRAM frame buffer
       │
       │  uDMA channel 13
       ▼
  [uDMA controller] ──── burst 4 bytes when FIFO has space ────▶ [SSI2 TX FIFO] ──▶ SPI pins ──▶ LEDs
                              ▲
                              │ DMA request signal
                         SSI2 TX FIFO draining
```

The SSI2 peripheral has a TX FIFO (8 entries deep on TM4C123). When it drains down to the arbitration threshold, it fires a **DMA request** on its dedicated uDMA channel. The uDMA controller responds by reading bytes from SRAM and writing them into the FIFO — completely autonomously.

---

## Ping-Pong Mode

uDMA has two descriptor slots per channel: **primary** and **alternate**. In ping-pong mode:

- The controller starts executing the **primary** descriptor
- When primary completes, it **automatically switches** to the **alternate** descriptor — with zero gap
- It then fires an interrupt
- The ISR can reload the primary descriptor while alternate is running, creating an endless pipeline

In this driver, ping-pong is used more simply: split a single frame buffer in half, put the first half in primary, the second half in alternate, and let them chain. No reloading needed — just a clean way to send one big buffer that might exceed the 1023-byte single-descriptor limit (the XFERSIZE field is 10 bits).

```
Primary descriptor:          Alternate descriptor:
buf[0 .. half-1]        →   buf[half .. len-1]
                ↘                              ↘
            auto-switch                    interrupt → dmaBusy=0
```

---

## The Control Table

```c
uint32_t ucControlTable[256] __attribute__((aligned(1024)));
```

The uDMA hardware finds its descriptors through a base address register (`UDMA_CTLBASE_R`). The table has a rigid layout mandated by the hardware:

- **128 primary entries** at offset 0
- **128 alternate entries** at offset 512 bytes

Each entry is **4 × uint32_t** (16 bytes):

```
[0]  Source end address      (last byte, not first)
[1]  Destination end address
[2]  Control word            (packed bitfield with sizes, increment, mode, count)
[3]  Reserved/unused
```

The **1024-byte alignment** requirement is because the hardware uses the base address plus a fixed index formula to locate channel N's descriptor — it assumes the table starts at an aligned boundary.

For channel 13, the primary descriptor lives at indices `[52..55]` (13×4), and alternate at `[52+128..55+128]` = `[180..183]`. The `CH13` and `CH13ALT` macros presumably encode these offsets.

### Why "end address" and not start?

Specific to TM4C uDMA design. The controller decrements an internal counter and adds offsets, so it needs to know where the *last* byte is upfront. That's why you see:

```c
ucControlTable[CH13] = (uint32_t)(dma_buf + dma_half - 1);  // end, not start
```

### The control word

```c
UDMA_DST_INC_NONE |   // destination doesn't increment — SSI DR is always same address
UDMA_DST_SIZE_8   |   // 8-bit destination writes
UDMA_SRC_INC_8    |   // source increments by 1 byte after each transfer
UDMA_SRC_SIZE_8   |   // 8-bit source reads
UDMA_ARBSIZE_4    |   // re-arbitrate every 4 bytes (matches FIFO granularity)
((count - 1) << 4)|   // transfer size minus one, 10-bit field
UDMA_MODE_PINGPONG    // ping-pong mode
```

`ARBSIZE_4` tells the DMA controller to release the bus after every 4-byte burst, giving other DMA channels a chance to run. It also matches natural SPI FIFO behavior — 4 bytes in, 4 bytes out.

---

## SSI2 Initialization (`SK9822_SPI_Init`)

### Clock gating

```c
SYSCTL_RCGCSSI_R  |= SSI2_CLK;
SYSCTL_RCGCGPIO_R |= PORTB_CLK;
delay = SYSCTL_RCGC2_R;   // dummy read — stall for ~2 clock cycles
```

On TM4C123, peripherals are clock-gated by default. You write a bit to `RCGC` (Run-mode Clock Gating Control) to enable them. The dummy read is a documented requirement — the peripheral needs a few cycles after the clock enable before you can safely access its registers. Reading any register creates the necessary stall without burning cycles in a counted loop.

### GPIO alternate function

```c
GPIO_PORTB_AFSEL_R |= PB4_7;           // hand pins to peripheral, not GPIO logic
GPIO_PORTB_PCTL_R   = ... | PB4_7_PCTL_SET;  // select which peripheral (AF2 = SSI2)
GPIO_PORTB_DEN_R   |= PB4_7;           // digital enable (not analog)
GPIO_PORTB_AMSEL_R  = 0;               // disable analog (ADC) on these pins
```

TM4C pins are multiplexed. `AFSEL` says "don't use me as GPIO," and `PCTL` selects *which* peripheral among the several that share that pin. The encoding (AF2 = SSI2 on PB4/PB7) comes directly from the datasheet's pin mux table.

### SSI configuration

```c
SSI2_CR1_R &= ~SSI_CR1_SSE;  // MUST disable SSI before changing any config register
SSI2_CR1_R &= ~SSI_CR1_MS;   // 0 = master mode
SSI2_CPSR_R = cpsdvsr;       // clock prescaler (must be even, ≥2)
SSI2_CR0_R |= (scr << 8) | SSI_CR0_DSS_8 | SSI_CR0_FRF_MOTO;
```

The SPI clock rate is: `f_SPI = f_SYS / (CPSDVSR × (1 + SCR))`. The caller passes both parameters to tune the rate. `FRF_MOTO` selects Motorola SPI frame format (CPOL=0, CPHA=0 by default), which is what SK9822 expects.

### Arming DMA before enabling SSI

```c
SSI2_DMACTL_R |= SSI_DMACTL_TXDMAE;  // route TX events to uDMA
// ... NVIC setup ...
SSI2_CR1_R |= SSI_CR1_SSE;           // enable SSI last
```

DMA is enabled on the SSI side *before* SSI itself turns on. This avoids a race where SSI enables and immediately fires a TX request before uDMA is ready to respond.

---

## uDMA Initialization (`SK9822_DMA_Init`)

```c
UDMA_CFG_R     = 0x01;                        // enable the uDMA controller itself
UDMA_CTLBASE_R = (uint32_t)ucControlTable;    // tell it where the descriptor table lives
```

### Channel mapping

```c
UDMA_CHMAP1_R = (UDMA_CHMAP1_R & ~0x00F00000) | 0x00200000;
```

Each uDMA channel can be connected to several possible peripherals. `CHMAP1` is a 32-bit register where each nibble (4 bits) selects the peripheral for one channel. Channel 13 lives in `CHMAP1` bits [23:20]. Writing `2` selects SSI2 TX — this encoding comes from Table 9-1 in the TM4C123 datasheet and is hardware-fixed.

### Channel reset sequence

```c
UDMA_ENACLR_R      = DMA_CH_BIT;   // disabled, not running
UDMA_PRIOCLR_R     = DMA_CH_BIT;   // normal (not high) priority
UDMA_ALTCLR_R      = DMA_CH_BIT;   // will start on primary descriptor
UDMA_USEBURSTCLR_R = DMA_CH_BIT;   // respond to single requests too, not just burst
UDMA_REQMASKCLR_R  = DMA_CH_BIT;   // unmask — let peripheral requests through
```

Each of these is a write-1-to-clear register (writing a bit clears that channel's flag without affecting others). This is the standard "reset to known state" sequence before you configure a channel.

---

## The Start Sequence and the REQMASK Safety Pattern

```c
UDMA_REQMASKSET_R = DMA_CH_BIT;  // BLOCK peripheral requests
// ... write descriptors to SRAM ...
UDMA_REQMASKCLR_R = DMA_CH_BIT;  // UNBLOCK
dmaBusy = 1;
UDMA_ENASET_R     = DMA_CH_BIT;  // ARM channel
```

This is a subtle but important safety pattern. If SSI2 is already running and its FIFO drains mid-descriptor-write, it could fire a DMA request at the exact moment you're halfway through writing a descriptor — the controller would read garbage. The mask temporarily blocks that peripheral's requests from reaching the channel, giving you an atomic window to commit all 8 words (two descriptors) before the channel is live.

The commented-out `__DSB()`/`__DMB()` calls are about the same concern at the CPU level — Cortex-M4 has a write buffer that can defer SRAM stores. In practice the REQMASK sandwich provides sufficient ordering, but the barriers are there as a documented escape hatch.

---

## The Interrupt Handler

```c
extern void DMA_Done_Callback(void);

void SSI2_Handler(void) {
    if(!(UDMA_CHIS_R & DMA_CH_BIT)) return;   // guard against spurious
    UDMA_CHIS_R = DMA_CH_BIT;                 // clear by writing 1

    if((ucControlTable[CH13ALT+2] & 0x7U) == 0) {   // mode bits == STOP?
        UDMA_ENACLR_R = DMA_CH_BIT;
        dmaBusy = 0;
        DMA_Done_Callback();                  // hook for next-frame build
    }
}
```

The handler fires on *both* descriptor completions (primary → alternate switch, and alternate completion), because ping-pong generates an interrupt each time. The primary completion is a no-op here — the transfer is already continuing in the alternate descriptor automatically.

For the alternate completion, the mode bits in the control word drop to `0b000` (STOP mode), which is the hardware's way of saying "this descriptor is exhausted." That's the signal that the entire frame is done.

`DMA_Done_Callback()` is provided by the application (defined in `main_sd.c` when `ISR_BUILD_ON_DMA_DONE` mode is selected). It runs the next frame's `BuildFrame()` immediately so the CPU can prepare column N+1 in parallel with the SPI hardware finishing column N.

The commented-out `while(SSI2_SR_R & SSI_SR_BSY)` is worth noting: uDMA completion means the FIFO has been *filled*, not that SPI has finished *clocking out*. If you reconfigured the pins or started a new frame immediately, you could clip the last byte. The busy-wait ensures the shift register fully empties first.

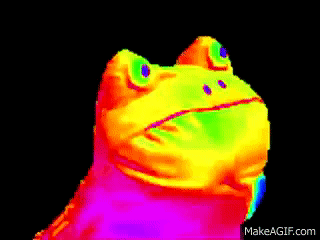
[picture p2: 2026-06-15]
Scripts/frog/frog.gif

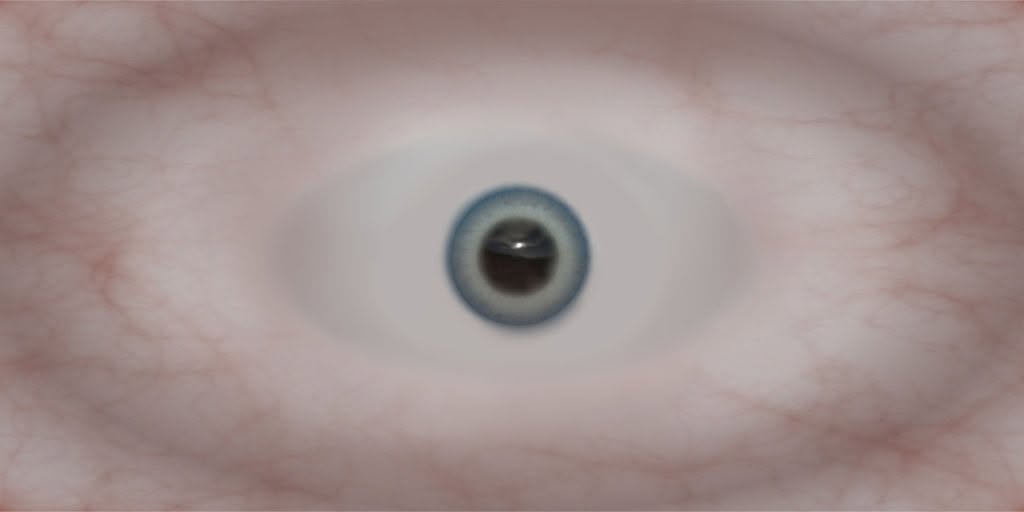
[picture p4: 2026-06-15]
Scripts/eye/eye.jpg

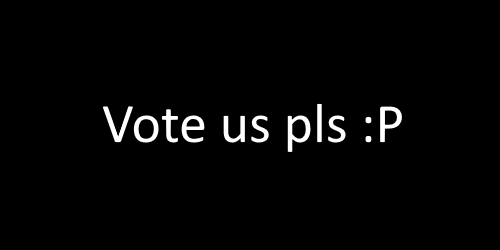
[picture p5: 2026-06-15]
Scripts/vote/vote.png

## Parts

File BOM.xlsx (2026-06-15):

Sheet: Parts
Bill of Materials |  |  | 2025-01-07 | "not free" means you have to buy it |  | "free sample" means you have to order it
ECE445L Spring 2025 |  |  | EE445L pays for the PCB | "Cabinet means in one of the six black cabinets in professsor's office (bring a print out of your SCH")
 |  |  |  | "Professor" means ask your professor quantity and style will vary (bring a print out of your SCH circuit)
Qty Note | REF DES Note (http://projects.ece.utexas.edu/valvano/wiki/doku.php?id=pcbartist:schematics) |  |  | "Box means in box in your professor's office (bring a print out of your SCH circuit)
Quantity | REF DES | Type | Description | Manufacturer | Mfg. P/N | Distributor | P/N | Unit cost | Cost | Where to get it? | Inventory
0 |  | ASM | 8-ohm speaker |  |  |  |  | $0.60 | $0.00 | professor
0 |  | ASM | 9V battery snap, T-type |  |  |  |  | $0.50 | $0.00 | Box
0 |  | ASM | Black case, 7.5" by 4.3" by 2.2" | Hammond | 1591ESBK | Mouser | 546-1591ES-BK | $5.18 | $0.00 | Box | http://www.hammondmfg.com/pdf/1591E.pdf
0 |  | ASM | Electret microphone | Panasonic |  |  |  | $0.50 | $0.00 | Cabinet
0 |  | CAP | Ceramic, X7R, 20%, 1 uF |  |  | Jameco | 81509 | $0.35 | $0.00 | Cabinet
0 |  | CAP | Ceramic, Z5U, -20/+80%, 0.47 uF | Kemet | C320C474M5U5TA | Digikey | 399-4309-ND | $0.40 | $0.00 | Cabinet
0 |  | CAP | Ceramic, Z5U, -20/+80%, 0.1 uF |  |  | Digikey | 399-4151-ND | $0.04 | $0.00 | Cabinet
0 |  | CAP | Ceramic, Z5U, -20/+80%, 0.033 uF |  |  | Digikey | 399-4298-ND | $0.40 | $0.00 | Cabinet
0 |  | CAP | Ceramic, Z5U, -20/+80%, 0.027uF |  |  |  |  | $0.40 | $0.00 | Cabinet
0 |  | CAP | Ceramic, Z5U, -20/+80%, 0.01 uF |  |  | Digikey | 399-4148-ND | $0.40 | $0.00 | Cabinet
0 |  | CAP | Ceramic, Z5U, -20/+80%, 4.7 nF |  |  | Digikey | 399-4188-ND | $0.40 | $0.00 | Cabinet
0 |  | CAP | Ceramic, Z5U, -20/+80%, 2.2 nF |  |  |  |  | $0.40 | $0.00 | Cabinet
0 |  | CAP | Ceramic, Z5U, -20/+80%, 1 nF |  |  |  |  | $0.40 | $0.00 | Cabinet
0 |  | CAP | Ceramic Z5U, -20/+80%, 470 pF |  |  |  |  | $0.03 | $0.00 | Cabinet
0 |  | CAP | Ceramic Z5U, -20/+80%, 330 pF |  |  |  |  | $0.03 | $0.00 | Cabinet
0 |  | CAP | Ceramic Z5U, -20/+80%, 220 pF |  |  |  |  | $0.03 | $0.00 | Cabinet
0 |  | CAP | Ceramic Z5U, -20/+80%, 100 pF |  |  |  |  | $0.03 | $0.00 | Cabinet
0 |  | CAP | Ceramic Z5U, -20/+80%, 22 pF |  |  | Jameco | 15405 | $0.03 | $0.00 | Cabinet
0 |  | CAP | Ceramic C0G, 10%, 10 pF | Murata 50V 5% | RDE5C1H100J0P1H03B | Digikey | 490-8629-ND | $0.31 | $0.00 | Cabinet | not required, we expect most students will create a system with the LaunchPad
0 |  | CAP-Tant | Tantalum, 16V, 20% 2.2 uF | AVX Corporation | TAP225M016CCS | Digikey | 478-8819-ND | $0.29 | $0.00 | Cabinet
0 |  | CAP-Tant | Tantalum, 16V, 10% 4.7 uF |  |  | Digikey | 478-1904-ND | $0.22 | $0.00 | Cabinet
0 |  | CAP-Tant | Tantalum, 20V, 10%, 1 uF |  |  | Digikey | 478-1833-ND | $0.32 | $0.00 | Cabinet
0 |  | CAP-Tant | Tantalum, 10UF 20V 10% |  |  | Digikey | 478-1840-ND | $0.56 | $0.00 | Cabinet
0 |  | CAP-Tant | Tantalum, 35V, 10%, 0.47 uF |  |  | Jameco | 33531 | $0.19 | $0.00 | Cabinet
0 |  | CAP-Elec | Electrolytic, 16V, 100 uF, cap 20%, ESR=20mV |  |  | Mouser | 661-APSF160E101MF05S | $0.38 | $0.00 | Cabinet
0 |  | CON | 2 to 40 pin 0.1 in header (price per pin) |  |  | AllElectronics | SHS-40 | $0.02 | $0.00 | Cabinet
0 |  | CON | 2-pin header |  |  | AllElectronics | SBH-2 | $0.10 | $0.00 | Cabinet
0 |  | CON | 2-pin jumper |  |  | AllElectronics | SBC-2 | $0.27 | $0.00 | Cabinet
0 |  | CON | 2-pin jumper |  |  | AllElectronics | SJ-1 | $0.10 | $0.00 | Cabinet
0 |  | CON | Test point, black | Keystone Electronics | 5001 | Digikey | 36-5001K-ND | $0.23 | $0.00 | Cabinet
0 |  | CON | Test point, orange | Keystone Electronics | 5003 | Digikey | 36-5003K-ND | $0.23 | $0.00 | Cabinet
0 |  | CON | Test point, yellow | Keystone Electronics | 5004 | Digikey | 36-5004K-ND | $0.23 | $0.00 | Cabinet
0 |  | CON | Test point, white | Keystone Electronics | 5002 | Digikey | 36-5002K-ND | $0.23 | $0.00 | Cabinet
0 |  | CON | Test point, blue | Keystone Electronics | 5117 | Digikey | 36-5117-ND | $0.23 | $0.00 | Cabinet
0 |  | CON | Test point, green | Keystone Electronics | 5116 | Digikey | 36-5116-ND | $0.23 | $0.00 | Cabinet
0 |  | CON | Test point, red | Keystone Electronics | 5000 | Digikey | 36-5000K-ND | $0.23 | $0.00 | Cabinet
0 |  | CON | 10-pin LCD connector | SamTec | BCS-110-L-S-TE | SamTec |  |  | $0.00 | Cabinet
0 |  | CON | 14-pin LCD connector | SamTec | BCS-114-L-S-TE | SamTec |  |  | $0.00 | Cabinet
0 |  | CON | 16-pin LCD connector | SamTec | BCS-116-L-S-TE | SamTec |  |  | $0.00 | Cabinet
0 |  | CON | 20-pin LCD connector | SamTec | BCS-120-L-S-TE | SamTec |  |  | $0.00 | Cabinet
0 |  | CON | Socket for micro SD card | Molex | 473340001 | Digikey | WM3288CT-ND | $4.02 | $0.00 | professor | do not use, rather included on ST7735
0 |  | CON | USB Mini-B socket, board mount, surface mount | Molex | 56579-0576 | Mouser | 538-56579-0576 | $2.46 | $0.00 | Cabinet
 |  | CON | Micro USB Type B, surface mount | Hirose Connector | ZX62D-B-5PA8(30) | Mouser | 798-ZX62D-B-5PA830 | $0.47 | $0.00 | Cabinet
0 |  | CON | USB Mini-B socket, board mount, through hole | Molex | 54819-0519 | Digikey | WM17115-ND | $0.65 | $0.00 | Cabinet
0 |  | CON | BoosterPack connector | FCI | 68021-208HLF | Digikey | 609-3243-ND | $0.26 | $0.00 | Cabinet
0 |  | CON | Logic Analyzer connector | FCI | 68021-208HLF | Digikey | 609-3344-ND | $0.27 | $0.00 | Cabinet
0 |  | CON | JTAG 1 by 5 male header |  |  |  |  | $0.29 | $0.00 | Cabinet
0 |  | CON | 10 pin 2mm socket for Xbee (need two) | SamTec | SQT-110-01-F-S | SamTec |  | $1.00 | $0.00 | Cabinet
0 |  | CON | DB9 serial connector, female, board mount |  |  | Jameco | 15771 | $0.65 | $0.00 | Cabinet
0 |  | CPU | TM4C123GH6PM 64-pin LQFP | TI | TM4C123GH6PMI | Mouser | 595-TM4C123GH6PMI | $11.55 | $0.00 | not required, we expect most students will create a system with the LaunchPad
0 |  | CRYS | NX5032GA-16.000000 | NDK | NX5032GA-16.000000 | Digikey | 644-1037-1-ND | $0.51 | $0.00 | Cabinet | not required, we expect most students will create a system with the LaunchPad
0 |  | DIODE | 1N914 diode | Fairchild | 1N914 | Digikey | 1N914B-ND | $0.05 | $0.00 | Cabinet
0 |  | IC | ACCELER DUAL-AX 2.0G 8PLCC | Analog Devices | ADXL202JQC | Quest Components | ADXL202JQC | $7.50 | $0.00 | professor
0 |  | IC | LM2937 3.3 V regulator TO220, 500mA | TI | LM2937ET-3.3/NOPB | Digikey | LM2937ET-3.3-ND | $1.17 | $0.00 | Cabinet
0 |  | IC | LP2950 3.3V regulator, 100 mA TO-92 | TI | LP2950-33LPRE3 | Digikey | 296-31455-1-ND | $0.19 | $0.00 | Cabinet
0 |  | IC | 78M05 500mA 5V TO-220 regulator | National | LM78M05 | Jameco | 192233 | $0.19 | $0.00 | Cabinet
0 |  | IC | OPA4350 quad op amp | TI | OPA4350 | TI |  |  | $0.00 | free sample
0 |  | IC | TLV5616 12-bit DAC | TI | TLV5616 | TI | TLV5616CP |  | $0.00 | Cabinet or free sample
0 |  | IC | TLV5618 dual 12-bit DAC | TI | TLV5618 | TI | TLV5618ACP |  | $0.00 | free sample
0 |  | IC | MAX539 12-bit DAC | Maxim-IC | MAX539 | Maxim | MAX539ACPA |  | $0.00 | free sample
0 |  | IC | MAX1247 12-bit ADC | Maxim-IC | MAX1247 | Maxim | MAX1247ACPE+ |  | $0.00 | free sample
0 |  | IC | INA122P instrumentation amp | TI | INA122P | TI | INA122P |  | $0.00 | Cabinet or free sample
0 |  | IC | OPA2350 dual op amp | TI | OPA2350PA | TI | OPA2350PA |  | $0.00 | Cabinet or free sample |  |  | 1 KD
0 |  | IC | TLC2274 quad op amp | TI | TLC2274ACN | TI | TLC2274ACN | $1.17 | $0.00 | free sample |  |  | 2 HD
0 |  | IC | TPA731 audio amp (pin 1 low) 700mW | TI | TPA731D | TI | TPA731D | $1.84 | $0.00 | Cabinet or free sample |  |  | 3 AD
0 |  | IC | TPA751 audio amp (pin 1 high) 700mW | TI | TPA751D | TI | TPA751D | $1.84 | $0.00 | free sample |  |  | 4 JD
0 |  | IC | LM4041CILPR shunt diode reference | TI | LM4041CILPR | TI | LM4041CILPR | $0.90 | $0.00 | Cabinet or free sample |  |  | 5 CD
0 |  | IC | AD8032 dual op amp | Analog Devices | AD8032ANZ | Analog Devices | AD8032ANZ | $4.47 | $0.00 | free sample |  |  | 6 BD
0 |  | IC | L293 Motor H bridge | TI | L293NE | Digikey | 296-9519-5-ND | $3.50 | $0.00 | not free |  |  | 7 MD
0 |  | IC | DRV8848 | TI | DRV8848PWP | TI
0 |  | IC | 74HC595 |  |  | Jameco | 46105 | $0.40 | $0.00 | Cabinet |  |  | 8 ED
0 |  | IC | 74HC165 |  |  | Jameco | 45495 | $0.30 | $0.00 | Cabinet |  |  | 9 FD
0 |  | IC | 74HCT125N | TI | SN74HCT125N | Mouser | 595-SN74HCT125N | $0.53 | $0.00 | Cabinet |  |  | 9 FD
0 |  | IC | RS232 driver | STMicroelectronics | ST232CN | Jameco | 2001171 | $0.58 | $0.00 | not free |  |  | 0 ND
0 |  | JACK | DC Power MALE 2.1mm |  |  | Jameco | 101179 | $0.55 | $0.00 | Cabinet |  |  | * LD
0 |  | JACK | Stereo Jack, or audio jack |  |  | AllElectronics | MJW-12 | $0.09 | $0.00 | Cabinet |  | 87YY3212A
0 |  | KEY | 3 by 4 common bus (D), keypad | Grayhill | 87YY3212A-506 | BGMicro | SWT1109 | $2.99 | $0.00 | Box | http://docs.bgmicro.com/pdf/swt1109.pdf
 |  | LCD | 84 by 48 LCD | Nokia | 5110 | Sparkfun | 10168 | $9.95 | $0.00 | not free
 |  | LCD | 18-bit color 128*160 1.8" TFT LCD display | Sitronix | ST7735R | Adafruit | 358 | $19.96 | $0.00 | not free
0 |  | LED | Green 2mA 5mm diffused | Avago Technologies | HLMP-4740 | Digikey | 516-1327-ND | $0.29 | $0.00 | Cabinet
0 |  | LED | Red 1.6V 1mA 5mm diffused | Avago Technologies | HLMP-D150 | Digikey | 516-1323-ND | $0.29 | $0.00 | Cabinet
0 |  | LED | Yellow 2mA 5mm diffused | Avago Technologies | HLMP-4719 | Digikey | 516-1326-ND | $0.29 | $0.00 | Cabinet
0 |  | LED | Orange 10mA 5mm diffused | Avago Technologies | HLMP-D401 | Digikey | 516-1330-ND | $0.29 | $0.00 | Cabinet
0 |  | LED | Blue 10mA 5mm diffused |  |  |  |  | $0.99 | $0.00 | Cabinet | warning, the blue LEDs are very bright
0 |  | PCB | PCB plus shipping | JLCPCB |  | JLCPCB |  | $20.00 | $0.00 | http://www.4pcb.com/
0 |  | POT | 20K LINEAR SLIDE POT |  |  |  |  | $0.33 | $0.00 | professor
0 |  | POT | 10 K one-turn potentiometer |  |  |  |  | $0.15 | $0.00 | Cabinet
0 |  | POT | 20 K one-turn potentiometer |  |  |  |  | $0.15 | $0.00 | Cabinet
0 |  | RES | Carbon 1/6W, 5%, 100 | Yageo | CFR-12JB-100R | Digikey | 100EBK-ND | $0.02 | $0.00 | Cabinet
0 |  | RES | Carbon 1/6W, 5%, 220 | Yageo | CFR-12JB-220R | Digikey | 220EBK-ND | $0.02 | $0.00 | Cabinet
0 |  | RES | Carbon 1/6W, 5%, 270 | Yageo | CFR-12JB-270R | Digikey | 270EBK-ND | $0.02 | $0.00 | Cabinet
0 |  | RES | Carbon 1/6W, 5%, 330 | Yageo | CFR-12JB-330R | Digikey | 330EBK-ND | $0.02 | $0.00 | Cabinet
0 |  | RES | Carbon 1/6W, 5%, 470 | Yageo | CFR-12JB-470R | Digikey | 470EBK-ND | $0.02 | $0.00 | Cabinet
0 |  | RES | Carbon 1/6W, 5%, 510 | Yageo | CFR-12JB-510R | Digikey | 510EBK-ND | $0.02 | $0.00 | Cabinet
0 |  | RES | Carbon 1/6W, 5%, 680 | Yageo | CFR-12JB-680R | Digikey | 680EBK-ND | $0.02 | $0.00 | Cabinet
0 |  | RES | Carbon 1/6W, 5%, 820 | Yageo | CFR-12JB-820R | Digikey | 820EBK-ND | $0.02 | $0.00 | Cabinet
0 |  | RES | Carbon 1/6W, 5%, 1K | Yageo | CFR-12JB-1K0 | Digikey | 1.0KEBK-ND | $0.02 | $0.00 | Cabinet
0 |  | RES | Carbon 1/6W, 5%, 1.2K | Yageo | CFR-12JB-1K2 | Digikey | 1.2KEBK-ND | $0.02 | $0.00 | Cabinet
0 |  | RES | Carbon 1/6W, 5%, 1.5K | Yageo | CFR-12JB-1K5 | Digikey | 1.5KEBK-ND | $0.02 | $0.00 | Cabinet
0 |  | RES | Carbon 1/6W, 5%, 1.8K | Yageo | CFR-12JB-1K8 | Digikey | 1.8KEBK-ND | $0.02 | $0.00 | Cabinet
0 |  | RES | Carbon 1/6W, 5%, 2.0K | Yageo | CFR-12JB-2K0 | Digikey | 2.0KEBK-ND | $0.02 | $0.00 | Cabinet
0 |  | RES | Carbon 1/6W, 5%, 2.2K | Yageo | CFR-12JB-2K2 | Digikey | 2.2KEBK-ND | $0.02 | $0.00 | Cabinet
0 |  | RES | Carbon 1/6W, 5%, 2.7K | Yageo | CFR-12JB-2K7 | Digikey | 2.7KEBK-ND | $0.02 | $0.00 | Cabinet
0 |  | RES | Carbon 1/6W, 5%, 3.3K | Yageo | CFR-12JB-3K3 | Digikey | 3.3KEBK-ND | $0.02 | $0.00 | Cabinet
0 |  | RES | Carbon 1/6W, 5%, 3.9K | Yageo | CFR-12JB-3K9 | Digikey | 3.9KEBK-ND | $0.02 | $0.00 | Cabinet
0 |  | RES | Carbon 1/6W, 5%, 4.7K | Yageo | CFR-12JB-4K7 | Digikey | 4.7KEBK-ND | $0.02 | $0.00 | Cabinet
0 |  | RES | Carbon 1/6W, 5%, 5.1K | Yageo | CFR-12JB-5K1 | Digikey | 5.1KEBK-ND | $0.02 | $0.00 | Cabinet
0 |  | RES | Carbon 1/6W, 5%, 5.6K | Yageo | CFR-12JB-5K6 | Digikey | 5.6KEBK-ND | $0.02 | $0.00 | Cabinet
0 |  | RES | Carbon 1/6W, 5%, 6.8K | Yageo | CFR-12JB-6K8 | Digikey | 6.8KEBK-ND | $0.02 | $0.00 | Cabinet
0 |  | RES | Carbon 1/6W, 5%, 8.2K | Yageo | CFR-12JB-8K2 | Digikey | 8.2KEBK-ND | $0.02 | $0.00 | Cabinet
0 |  | RES | Carbon 1/6W, 5%, 10K | Yageo | CFR-12JB-10K | Digikey | 10KEBK-ND | $0.02 | $0.00 | Cabinet
0 |  | RES | Carbon 1/6W, 5%, 12K | Yageo | CFR-12JB-12K | Digikey | 12KEBK-ND | $0.02 | $0.00 | Cabinet
0 |  | RES | Carbon 1/6W, 5%, 15K | Yageo | CFR-12JB-15K | Digikey | 15KEBK-ND | $0.02 | $0.00 | Cabinet | http://www.kemet.com/kemet/web/homepage/kechome.nsf/vapubfiles/F3101_GoldMax.pdf/$file/F3101_GoldMax.pdf
0 |  | RES | Carbon 1/6W, 5%, 18K | Yageo | CFR-12JB-18K | Digikey | 18KEBK-ND | $0.02 | $0.00 | Cabinet
0 |  | RES | Carbon 1/6W, 5%, 20K | Yageo | CFR-12JB-20K | Digikey | 20KEBK-ND | $0.02 | $0.00 | Cabinet
0 |  | RES | Carbon 1/6W, 5%, 22K | Yageo | CFR-12JB-22K | Digikey | 22KEBK-ND | $0.02 | $0.00 | Cabinet
0 |  | RES | Carbon 1/6W, 5%, 27K | Yageo | CFR-12JB-27K | Digikey | 27KEBK-ND | $0.02 | $0.00 | Cabinet
0 |  | RES | Carbon 1/6W, 5%, 36K | Yageo | CFR-12JB-36K | Digikey | 36KEBK-ND | $0.02 | $0.00 | Cabinet
0 |  | RES | Carbon 1/6W, 5%, 33K | Yageo | CFR-12JB-33K | Digikey | 33KEBK-ND | $0.02 | $0.00 | Cabinet
0 |  | RES | Carbon 1/6W, 5%, 39K | Yageo | CFR-12JB-39K | Digikey | 39KEBK-ND | $0.02 | $0.00 | Cabinet
0 |  | RES | Carbon 1/6W, 5%, 47K | Yageo | CFR-12JB-47K | Digikey | 47KEBK-ND | $0.02 | $0.00 | Cabinet
0 |  | RES | Carbon 1/6W, 5%, 51K | Yageo | CFR-12JB-51K | Digikey | 51KEBK-ND | $0.02 | $0.00 | Cabinet
0 |  | RES | Carbon 1/6W, 5%, 56K | Yageo | CFR-12JB-56K | Digikey | 56KEBK-ND | $0.02 | $0.00 | Cabinet
0 |  | RES | Carbon 1/6W, 5%, 68K | Yageo | CFR-12JB-68K | Digikey | 68KEBK-ND | $0.02 | $0.00 | Cabinet
0 |  | RES | Carbon 1/6W, 5%, 82K | Yageo | CFR-12JB-82K | Digikey | 82KEBK-ND | $0.02 | $0.00 | Cabinet
0 |  | RES | Carbon 1/6W, 5%, 100K | Yageo | CFR-12JB-100K | Digikey | 100KEBK-ND | $0.02 | $0.00 | Cabinet
0 |  | RES | Carbon 1/6W, 5%, 120K | Yageo | CFR-12JB-120K | Digikey | 120KEBK-ND | $0.02 | $0.00 | Cabinet
0 |  | RES | Carbon 1/6W, 5%, 150K | Yageo | CFR-12JB-150K | Digikey | 150KEBK-ND | $0.02 | $0.00 | Cabinet
0 |  | RES | Carbon 1/6W, 5%, 180K | Yageo | CFR-12JB-180K | Digikey | 180KEBK-ND | $0.02 | $0.00 | Cabinet
0 |  | RES | Carbon 1/6W, 5%, 200K | Yageo | CFR-12JB-200K | Digikey | 200KEBK-ND | $0.02 | $0.00 | Cabinet
0 |  | RES | Carbon 1/6W, 5%, 220K | Yageo | CFR-12JB-220K | Digikey | 220KEBK-ND | $0.02 | $0.00 | Cabinet
0 |  | RES | Carbon 1/6W, 5%, 240K | Yageo | CFR-12JB-240K | Digikey | 240KEBK-ND | $0.02 | $0.00 | Cabinet
0 |  | RES | Carbon 1/6W, 5%, 270K | Yageo | CFR-12JB-270K | Digikey | 270KEBK-ND | $0.02 | $0.00 | Cabinet
0 |  | RES | Carbon 1/6W, 5%, 330K | Yageo | CFR-12JB-330K | Digikey | 330KEBK-ND | $0.02 | $0.00 | Cabinet
0 |  | RES | Carbon 1/6W, 5%, 390K | Yageo | CFR-12JB-390K | Digikey | 390KEBK-ND | $0.02 | $0.00 | Cabinet
0 |  | RES | Carbon 1/6W, 5%, 470K | Yageo | CFR-12JB-470K | Digikey | 470KEBK-ND | $0.02 | $0.00 | Cabinet
0 |  | RES | Carbon 1/6W, 5%, 510K | Yageo | CFR-12JB-510K | Digikey | 510KEBK-ND | $0.02 | $0.00 | Cabinet
0 |  | RES | Carbon 1/6W, 5%, 560K | Yageo | CFR-12JB-560K | Digikey | 560KEBK-ND | $0.02 | $0.00 | Cabinet
0 |  | RES | Carbon 1/6W, 5%, 680K | Yageo | CFR-12JB-680K | Digikey | 680KEBK-ND | $0.02 | $0.00 | Cabinet
0 |  | RES | Carbon 1/6W, 5%, 820K | Yageo | CFR-12JB-820K | Digikey | 820KEBK-ND | $0.02 | $0.00 | Cabinet
0 |  | RES | Carbon 1/6W, 5%, 1M | Yageo | CFR-12JB-1M0 | Digikey | 1.0MEBK-ND | $0.02 | $0.00 | Cabinet
0 |  | RES | Carbon 1/6W, 5%, 10M | Yageo | CFR-12JB-10M | Digikey | 10MEBK-ND | $0.02 | $0.00 | Cabinet
 |  | SW | Tactile Switch, surface mount | C&K Components | KSC353JLFG | Mouser | 611-KSC353JLFG | $0.86 | $0.00 | Cabinet
0 |  | SW | B3F tactile push button switch | Omron Electronics | B3F-1052 | Digikey | SW405-ND | $0.17 | $0.00 | Cabinet
0 |  | SW | Black Off board momentary push buttom |  |  |  |  | $0.35 | $0.00 | Cabinet
0 |  | SW | Red Off board momentary push buttom |  |  |  |  | $0.35 | $0.00 | Cabinet
0 |  | SW | On/off power switch |  |  | BGMicro | SWT1010 | $0.85 | $0.00 | Cabinet
0 |  | TRAN | PN2222 NPN transistor | Fairchild Semiconductor | PN2222 | Digikey | PN2222BU-ND | $0.13 | $0.00 | Cabinet | be careful to get pins 1 and 3 correct, there are two versions of the chip: 2N2222 and PN2222
0 |  | TRAN | TIP120 Darlington NPN, TO220 | Fairchild | TIP120 | Digikey | TIP120-ND | $0.68 | $0.00 | Cabinet
0 |  | TRAN | TIP125 Darlington PNP, TO220 | Fairchild | TIP125 | Digikey | TIP125TU-ND | $0.67 | $0.00 | Cabinet
0 |  | TRAN | IRF540 MOSFET N-channel, TO220 |  | IRF540 | Digikey | IRF540NPBF-ND | $1.95 | $0.00 | professor
0 |  | TRAN | IRLD120PBF | N-MOSFET | DIP-4 | Mouser | 844-IRLD120PBF | $1.58 | $0.00

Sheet: BOM
 |  | TOTAL COST: | 56.096
Quantity | REF DES | Type | Description | Manufacturer | Mfg. P/N | Distributor | P/N | Unit cost | Cost | Where to get it?
M HW
1 | Slip ring | na | Allows wires through spinning parts | n/a | n/a | Ebay | n/a | 7.5 | 7.5 | Ebay. Made deal with seller for 2 for $15, 1 was used
1 | Motor | Brushless | TT Motor TEC3650 6500RPM 36mm x 50mm High Torque Brushless 12V DC Motor | TEC | TEC3650 | Ebay | TEC3650 | 12.92 | 12.92 | NEW! TT Motor TEC3650 6500RPM 36mm x 50mm High Torque Brushless 12V DC Motor | eBay (https://www.ebay.com/itm/235972301407)
1 | Resin Gear | Resin | Resign gear that connects to motor | Jett Vanbrocklin | n/a | Jett Vanbrocklin | n/a | 1 | 1.00 | n/a
2 | Plywood Sheets | Wood | 12x12 3mm Laser Cut wood | Jett Vanbrocklin | n/a | TIW | n/a | 3.00 | 6.00 | n/a
1 | BTF-LIGHTING SK9822 | LED | Individually Addressable 3.3ft 1m 144 Pixels/LEDs Non-Waterproof Black PCB Data and Clock Separately DC5V Full Color | BTF-LIGHTING | SK9822 | Amazon | n/a | 21.99 | 21.99 | Amazon (https://www.amazon.com/dp/B07BPX2KFD)
1 | usb-c conn | USBC | UCBC connector | DWEII | Type-C PD3.0 QC | Amazon | n/a | 2 | 2.00 | Link (https://www.amazon.com/dp/B0DBPP52FD?ref=ppx_yo2ov_dt_b_fed_asin_title&th=1)
PCB HW
1 | TPS56628DDAR | Buck | Buck Switch Regulator IC | Texas Instruments | TPS56628DDAR | DigiKey | 296-40815-1-ND | 1.52 | 1.52 | TPS56628DDAR Texas Instruments | Integrated Circuits (ICs) | DigiKey (https://www.digikey.com/en/products/detail/texas-instruments/TPS56628DDAR/4505997)
1 | 1217AS-H-3R3N=P3 | Inductor | 3.3 µH Shielded Drum Core, Wirewound Inductor 6.8 A 14.4mOhm Max Nonstandard | Murata Electronics | 1217AS-H-3R3N=P3 | DigiKey | 490-10789-1-ND | 0.54 | 0.54 | 1217AS-H-3R3N=P3 Murata Electronics | Inductors, Coils, Chokes | DigiKey (https://www.digikey.com/en/products/detail/murata-electronics/1217AS-H-3R3N-P3/5271430)
1 | LMR51635XFDDCR | Buck | Buck Switching Regulator IC Positive Adjustable 0.8V 1 Output 3.5A SOT-23-6 Thin, TSOT-23-6 | Texas Instruments | LMR51635XFDDCR | DigiKey | 296-LMR51635XFDDCRCT-ND | 1.61 | 1.61 | LMR51635XFDDCR Texas Instruments | Integrated Circuits (ICs) | DigiKey (https://www.digikey.com/en/products/detail/texas-instruments/LMR51635XFDDCR/25991384)
1 | IFDC5050HZER150M | Inductor | 15 µH Shielded Wirewound Inductor 7.1 A 27mOhm Max Nonstandard | Vishay Dale | IFDC5050HZER150M | DigiKey | 541-IFDC5050HZER150MCT-ND | 0.58 | 0.58 | IFDC5050HZER150M Vishay Dale | Inductors, Coils, Chokes | DigiKey (https://www.digikey.com/en/products/detail/vishay-dale/IFDC5050HZER150M/22475115)
1 | 74AXP2T45DCH | Level Shifter | Voltage Level Translator Bidirectional 2 Circuit 1 Channel 8-VSSOP | Nexperia USA Inc. | 74AXP2T45DCH | DigiKey | 1727-74AXP2T45DCHTR-ND | 0.436 | 0.44 | https://www.digikey.com/en/products/detail/nexperia-usa-inc/74AXP2T45DCH/13575029
1 | EK-TM4C123GXL |  | MCU | Texas Instruments | EK-TM4C123GXL | Texas Instruments | EK-TM4C123GXL | $6.78 | $0.00 | owned | TM4C123GH6PM data sheet, product information and support | TI.com (https://www.ti.com/product/TM4C123GH6PM)
1 | ST7735R |  | TFT Screen | Adafruit | ST7735R | Adafruit | ST7735R | $19.95 | $0.00 | owned | 1.8 Color TFT LCD display with MicroSD Card Breakout [ST7735R] : Adafruit Industries, Unique & fun DIY electronics and kits (https://www.adafruit.com/product/358)
NOTE: Did not include passives, resistors, capacitors, esp, DAC, AMP, buttons, LEDS, and other things gotten from checkout desk or left unused |  |  |  |  |  |  | Total (not including what isn't counted for the competiton price) | 56.10

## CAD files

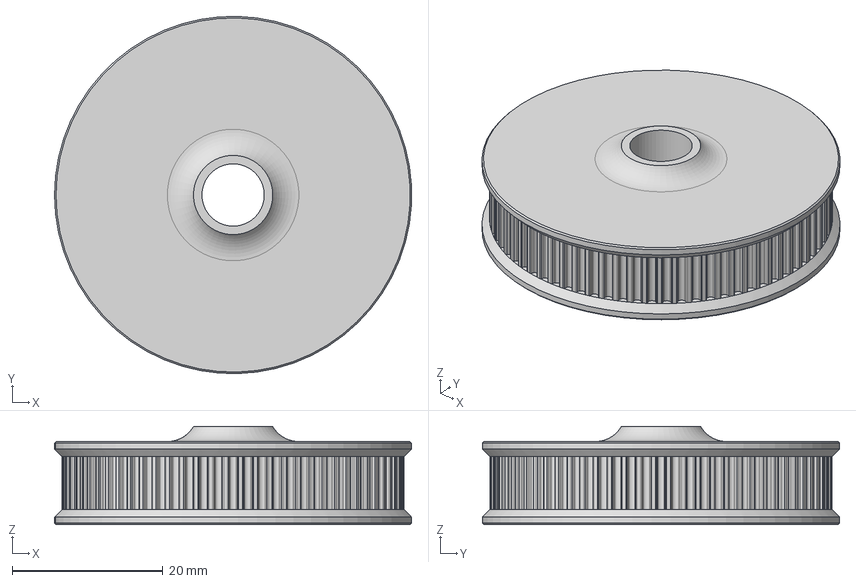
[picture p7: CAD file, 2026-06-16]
Mechanical/Axle Pulley.step
47.3 x 47.3 x 13.0 mm

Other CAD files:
Firmware/src/Debug/Data/baby/baby_palette.obj
Firmware/src/Debug/Data/boi/boi_data.obj
Firmware/src/Debug/Data/cat_space/cat_space_palette.obj
Firmware/src/Debug/Data/dermot/dermot_palette.obj
Firmware/src/Debug/Data/dot/dot_palette.obj
Firmware/src/Debug/Data/eye/eye_data.obj
Firmware/src/Debug/Data/frog/frog_data.obj
Firmware/src/Debug/Data/lebron/lebron_palette.obj
Firmware/src/Debug/Data/map_data.obj
Firmware/src/Debug/Data/vote/vote_palette.obj
Firmware/src/Debug/Drivers/src/LCD.obj
Firmware/src/Debug/Data/baby/baby_data.obj
Firmware/src/Debug/Data/boi/boi_palette.obj
Firmware/src/Debug/Data/cat_space/cat_space_data.obj
Firmware/src/Debug/Data/dermot/dermot_data.obj
Firmware/src/Debug/Data/dot/dot_data.obj
Firmware/src/Debug/Data/eye/eye_palette.obj
Firmware/src/Debug/Data/frog/frog_palette.obj
Firmware/src/Debug/Data/globe_old/globe_data.obj
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

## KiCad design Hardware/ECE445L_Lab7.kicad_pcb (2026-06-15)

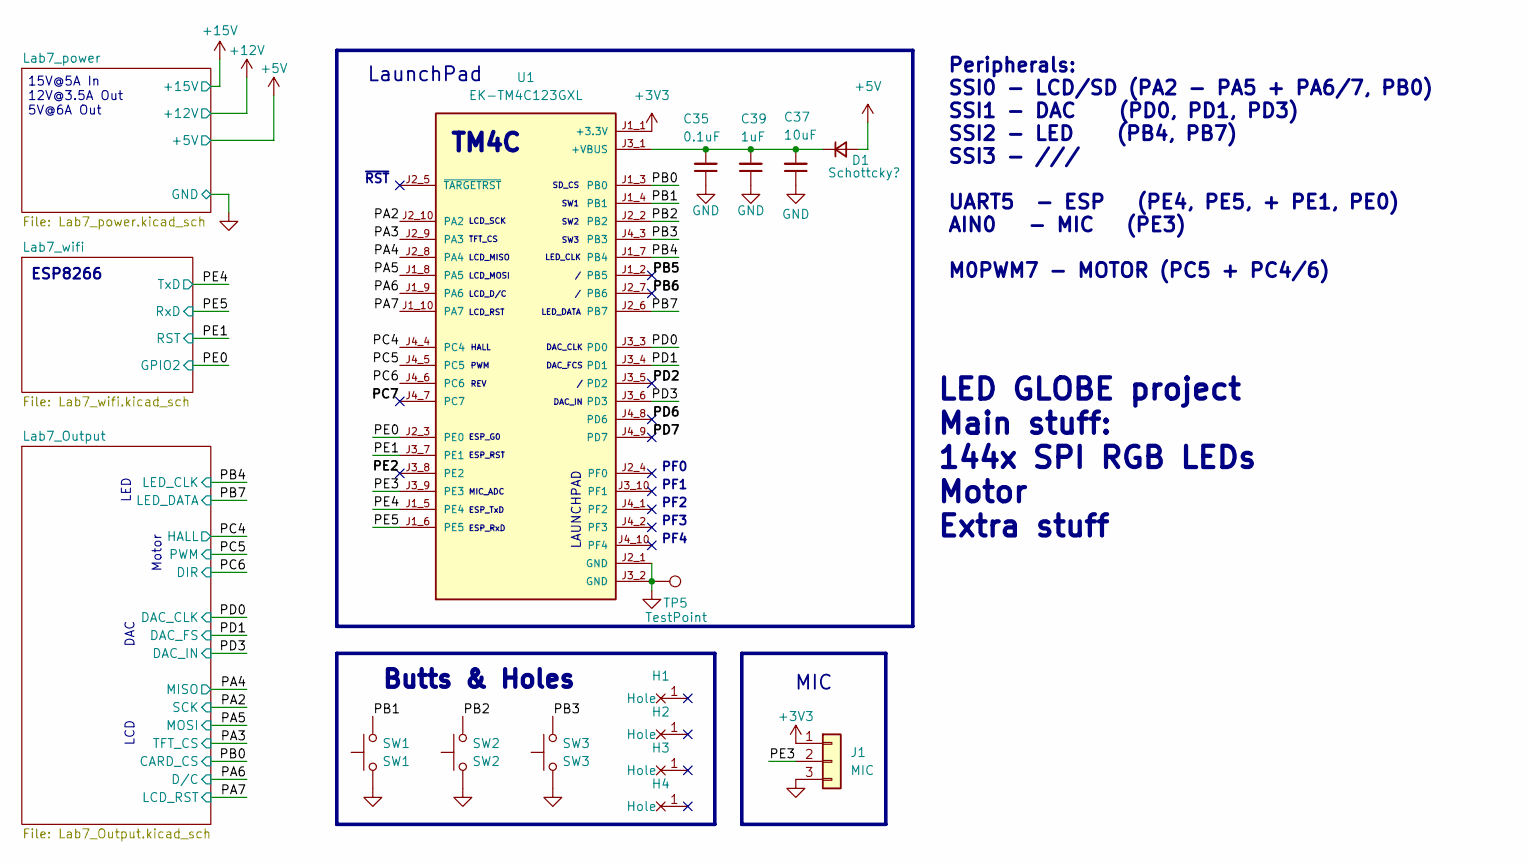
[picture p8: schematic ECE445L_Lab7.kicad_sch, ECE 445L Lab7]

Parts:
C35: 0.1uF; C_Axial_200mil
C37: 10uF; C_Axial_200mil
C39: 1uF; C_Axial_200mil
D1: Schottcky?; D_DO-34_SOD68_P7.62mm_Horizontal
H1, H2, H3, H4: MountingHole_4_40
J1: MIC; PinHeader_1x03_P2.54mm_Vertical
SW1: SW1; SW_PUSH_6mm
SW2: SW2; SW_PUSH_6mm
SW3: SW3; SW_PUSH_6mm
TP5: TestPoint; PinHeader_1x01_P2.54mm_Vertical
U1: EK-TM4C123GXL; ti_EKTM4C123GXL

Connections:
+3V3: J1.1, U1.J1_1 (+3.3V); also elsewhere on the board
+5V: D1.2 (A); also elsewhere on the board
/PA2: U1.J2_10 (PA2); also elsewhere on the board
/PA3: U1.J2_9 (PA3); also elsewhere on the board
/PA4: U1.J2_8 (PA4); also elsewhere on the board
/PA5: U1.J1_8 (PA5); also elsewhere on the board
/PA6: U1.J1_9 (PA6); also elsewhere on the board
/PA7: U1.J1_10 (PA7); also elsewhere on the board
/PB0: U1.J1_3 (PB0); also elsewhere on the board
/PB1: SW1.2, U1.J1_4 (PB1)
/PB2: SW2.2, U1.J2_2 (PB2)
/PB3: SW3.2, U1.J4_3 (PB3)
/PB4: U1.J1_7 (PB4); also elsewhere on the board
/PB5: U1.J1_2 (PB5)
/PB6: U1.J2_7 (PB6)
/PB7: U1.J2_6 (PB7); also elsewhere on the board
/PC4: U1.J4_4 (PC4); also elsewhere on the board
/PC5: U1.J4_5 (PC5); also elsewhere on the board
/PC6: U1.J4_6 (PC6); also elsewhere on the board
/PC7: U1.J4_7 (PC7)
/PD0: U1.J3_3 (PD0); also elsewhere on the board
/PD1: U1.J3_4 (PD1); also elsewhere on the board
/PD2: U1.J3_5 (PD2)
/PD3: U1.J3_6 (PD3); also elsewhere on the board
/PD6: U1.J4_8 (PD6)
/PD7: U1.J4_9 (PD7)
/PE0: U1.J2_3 (PE0); also elsewhere on the board
/PE1: U1.J3_7 (PE1); also elsewhere on the board
/PE2: U1.J3_8 (PE2)
/PE3: J1.2, U1.J3_9 (PE3)
/PE4: U1.J1_5 (PE4); also elsewhere on the board
/PE5: U1.J1_6 (PE5); also elsewhere on the board
GND: C35.1, C37.1, C39.1, J1.3, SW1.1, SW2.1, SW3.1, TP5.1, U1.J2_1 (GND), U1.J3_2 (GND); also elsewhere on the board
unnamed: C35.2, C37.2, C39.2, D1.1 (K), U1.J3_1 (+VBUS)

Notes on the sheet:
Motor
PF0
HALL PWM REV
TM4C
DAC
LCD
LED_CLK / / LED_DATA
SD_CS SW1 SW2 SW3
PF2
15V@5A In 12V@3.5A Out 5V@6A Out
ESP8266
LaunchPad
LED GLOBE project Main stuff: 144x SPI RGB LEDs Motor Extra stuff
LAUNCHPAD
ESP_G0 ESP_RST MIC_ADC ESP_TxD ESP_RxD
DAC_CLK DAC_FCS / DAC_IN
Peripherals: SSI0 - LCD/SD (PA2 - PA5 + PA6/7, PB0) SSI1 - DAC (PD0, PD1, PD3) SSI2 - LED (PB4, PB7) SSI3 - /// UART5 - ESP (PE4, PE5, + PE1, PE0) AIN0 - MIC (PE3) M0PWM7 - MOTOR (PC5 + PC4/6)
PF4
PF1
~{RST}
PF3
LED
Butts & Holes
MIC
LCD_SCK TFT_CS LCD_MISO LCD_MOSI LCD_D/C LCD_RST

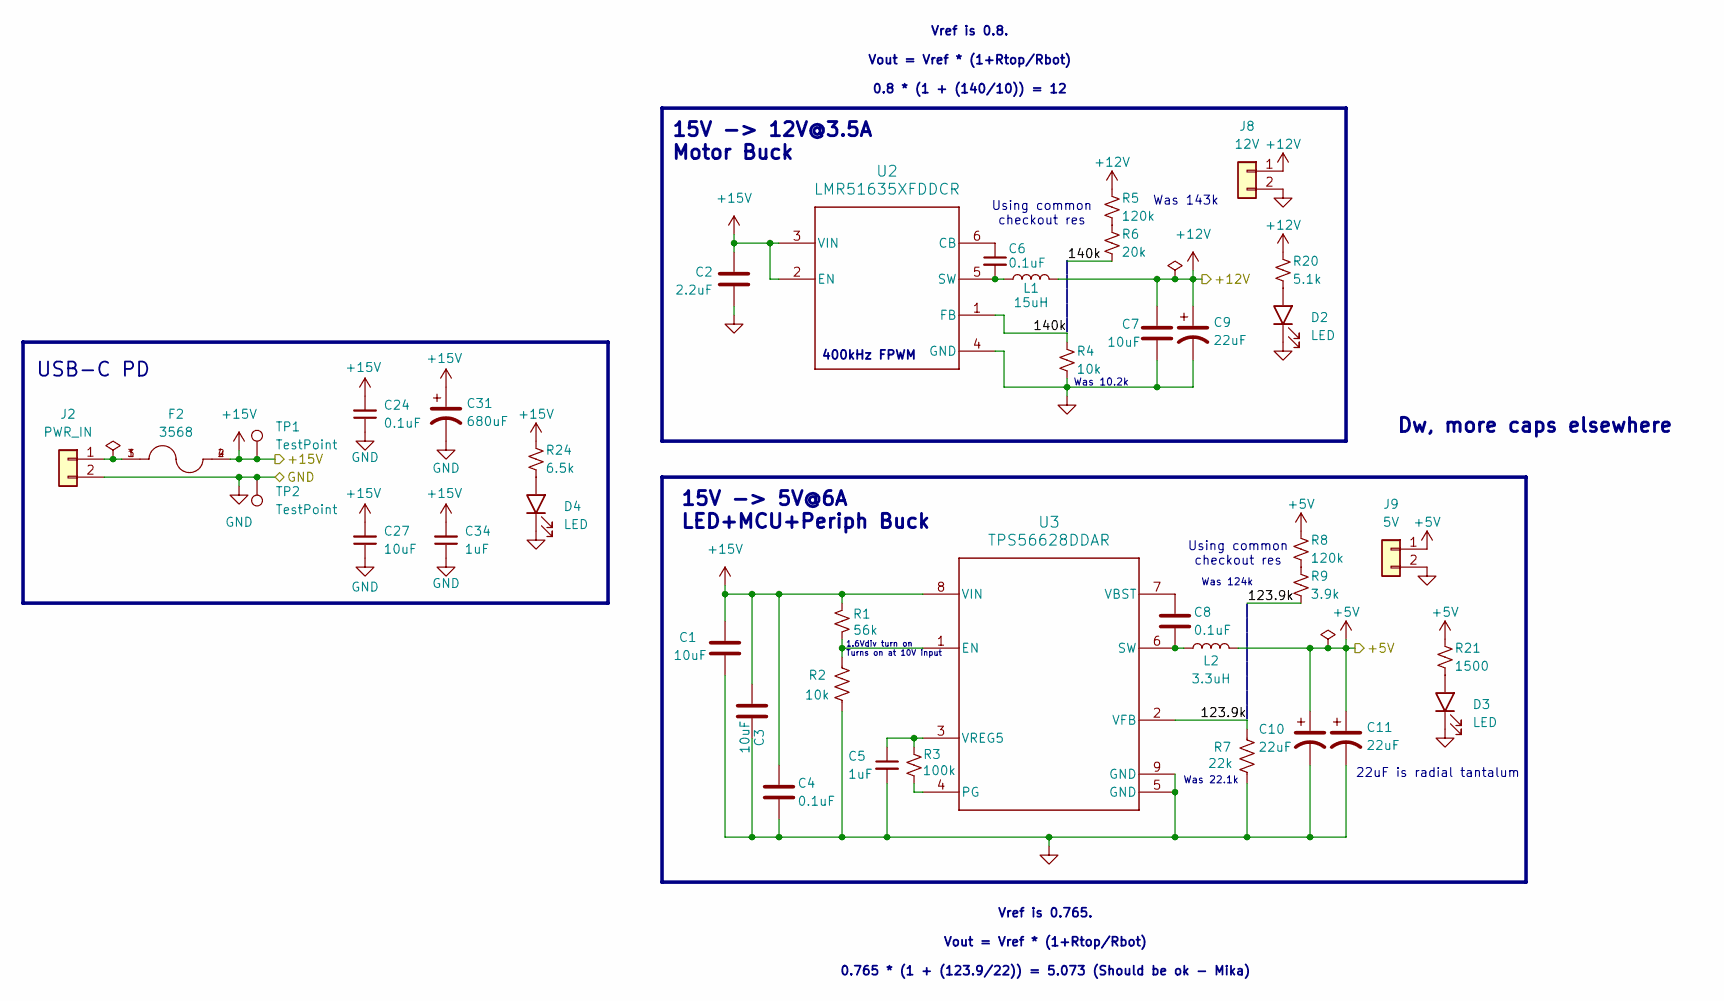
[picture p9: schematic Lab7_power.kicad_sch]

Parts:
C1, C3, C7, C27: 10uF; C_Axial_200mil
C2: 2.2uF; C_Axial_200mil
C4, C6, C8, C24: 0.1uF; C_Axial_200mil
C5, C34: 1uF; C_Axial_200mil
C9, C10, C11: 22uF; CP_Radial_Tantal200mil
C31: 680uF; C_Radial_D10.0mm_H20.0mm_P5.00mm
D2, D3, D4: LED; LED_D5.0mm
F2: 3568; FUSE_3568; PARTREV C
J2: PWR_IN; PinHeader_1x02_P2.54mm_Vertical
J8: 12V; PinHeader_1x02_P2.54mm_Vertical
J9: 5V; PinHeader_1x02_P2.54mm_Vertical
L1: 15uH; IFDC5050HZER150M
L2: 3.3uH; 1217AS
R1: 56k; R_Axial_DIN0204_L3.6mm_D1.6mm_P7.62mm_Horizontal
R2, R4: 10k; R_Axial_DIN0204_L3.6mm_D1.6mm_P7.62mm_Horizontal
R3: 100k; R_Axial_DIN0204_L3.6mm_D1.6mm_P7.62mm_Horizontal
R5, R8: 120k; R_Axial_DIN0204_L3.6mm_D1.6mm_P7.62mm_Horizontal
R6: 20k; R_Axial_DIN0204_L3.6mm_D1.6mm_P7.62mm_Horizontal
R7: 22k; R_Axial_DIN0204_L3.6mm_D1.6mm_P7.62mm_Horizontal
R9: 3.9k; R_Axial_DIN0204_L3.6mm_D1.6mm_P7.62mm_Horizontal
R20: 5.1k; R_Axial_DIN0204_L3.6mm_D1.6mm_P7.62mm_Horizontal
R21: 1500; R_Axial_DIN0204_L3.6mm_D1.6mm_P7.62mm_Horizontal
R24: 6.5k; R_Axial_DIN0204_L3.6mm_D1.6mm_P7.62mm_Horizontal
TP1, TP2: TestPoint; PinHeader_1x01_P2.54mm_Vertical
U2: LMR51635XFDDCR; TSOT-23-6_HandSoldering
U3: TPS56628DDAR; TI_SO-PowerPAD-8

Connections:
+5V: C10.1, C11.1, J9.1, L2.2, R8.1, R21.1; also elsewhere on the board
+12V: C7.1, C9.1, J8.1, L1.2, R5.1, R20.1; also elsewhere on the board
+15V: C1.1, C2.1, C3.1, C4.1, C24.2, C27.2, C31.1, C34.2, F2.2, F2.4, R1.2, R24.1, TP1.1, U2.2 (EN), U2.3 (VIN), U3.8 (VIN)
/Lab7_power/123.9k: R7.1, R9.2, U3.2 (VFB)
/Lab7_power/140k: R4.1, R6.2, U2.1 (FB)
GND: C1.2, C2.2, C3.2, C4.2, C5.2, C7.2, C9.2, C10.2, C11.2, C24.1, C27.1, C31.2, C34.1, D2.1 (K), D3.1 (K), D4.1 (K), J2.2, J8.2, J9.2, R2.2, R4.2, R7.2, TP2.1, U2.4 (GND), U3.5 (GND), U3.9 (GND); also elsewhere on the board
unnamed: D2.2 (A), R20.2
unnamed: D3.2 (A), R21.2
unnamed: D4.2 (A), R24.2
unnamed: F2.1, F2.3, J2.1
unnamed: R5.2, R6.1
unnamed: R8.2, R9.1
unnamed: C6.1, U2.6 (CB)
unnamed: C6.2, L1.1, U2.5 (SW)
unnamed: R1.1, R2.1, U3.1 (EN)
unnamed: R3.1, U3.4 (PG)
unnamed: C8.2, L2.1, U3.6 (SW)
unnamed: C8.1, U3.7 (VBST)
unnamed: C5.1, R3.2, U3.3 (VREG5)

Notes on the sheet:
| | | | |
Vref is 0.765. Vout = Vref * (1+Rtop/Rbot) 0.765 * (1 + (123.9/22)) = 5.073 (Should be ok - Mika)
Was 124k
Dw, more caps elsewhere
400kHz FPWM
USB-C PD
Using common checkout res
15V -> 12V@3.5A Motor Buck
| | | | | | | |
Vref is 0.8. Vout = Vref * (1+Rtop/Rbot) 0.8 * (1 + (140/10)) = 12
22uF is radial tantalum
Was 10.2k
Was 143k
1.6Vdiv turn on Turns on at 10V input
Was 22.1k
15V -> 5V@6A LED+MCU+Periph Buck

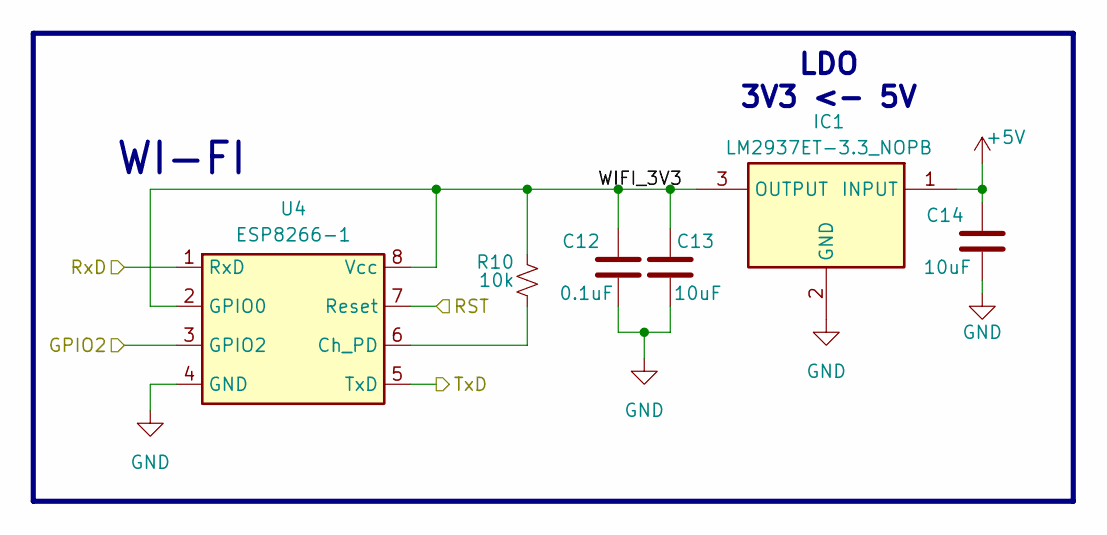
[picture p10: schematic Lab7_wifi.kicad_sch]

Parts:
C12: 0.1uF; C_Axial_200mil
C13, C14: 10uF; C_Axial_200mil
IC1: LM2937ET-3.3_NOPB; TO254P470X1028X1955-3P; Mouser Part Number 926-LM2937ET-3.3NOPB
R10: 10k; R_Axial_DIN0204_L3.6mm_D1.6mm_P7.62mm_Horizontal
U4: ESP8266-1; PinHeader_2x04_P2.54mm_Vertical

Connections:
+5V: C14.1, IC1.1 (INPUT); also elsewhere on the board
/Lab7_wifi/WIFI_3V3: C12.1, C13.1, IC1.3 (OUTPUT), R10.1, U4.2 (GPIO0), U4.8 (Vcc)
/PE0: U4.3 (GPIO2); also elsewhere on the board
/PE1: U4.7 (Reset); also elsewhere on the board
/PE4: U4.5 (TxD); also elsewhere on the board
/PE5: U4.1 (RxD); also elsewhere on the board
GND: C12.2, C13.2, C14.2, IC1.2 (GND), U4.4 (GND); also elsewhere on the board
unnamed: R10.2, U4.6 (Ch_PD)

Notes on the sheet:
WI-FI
LDO 3V3 <- 5V

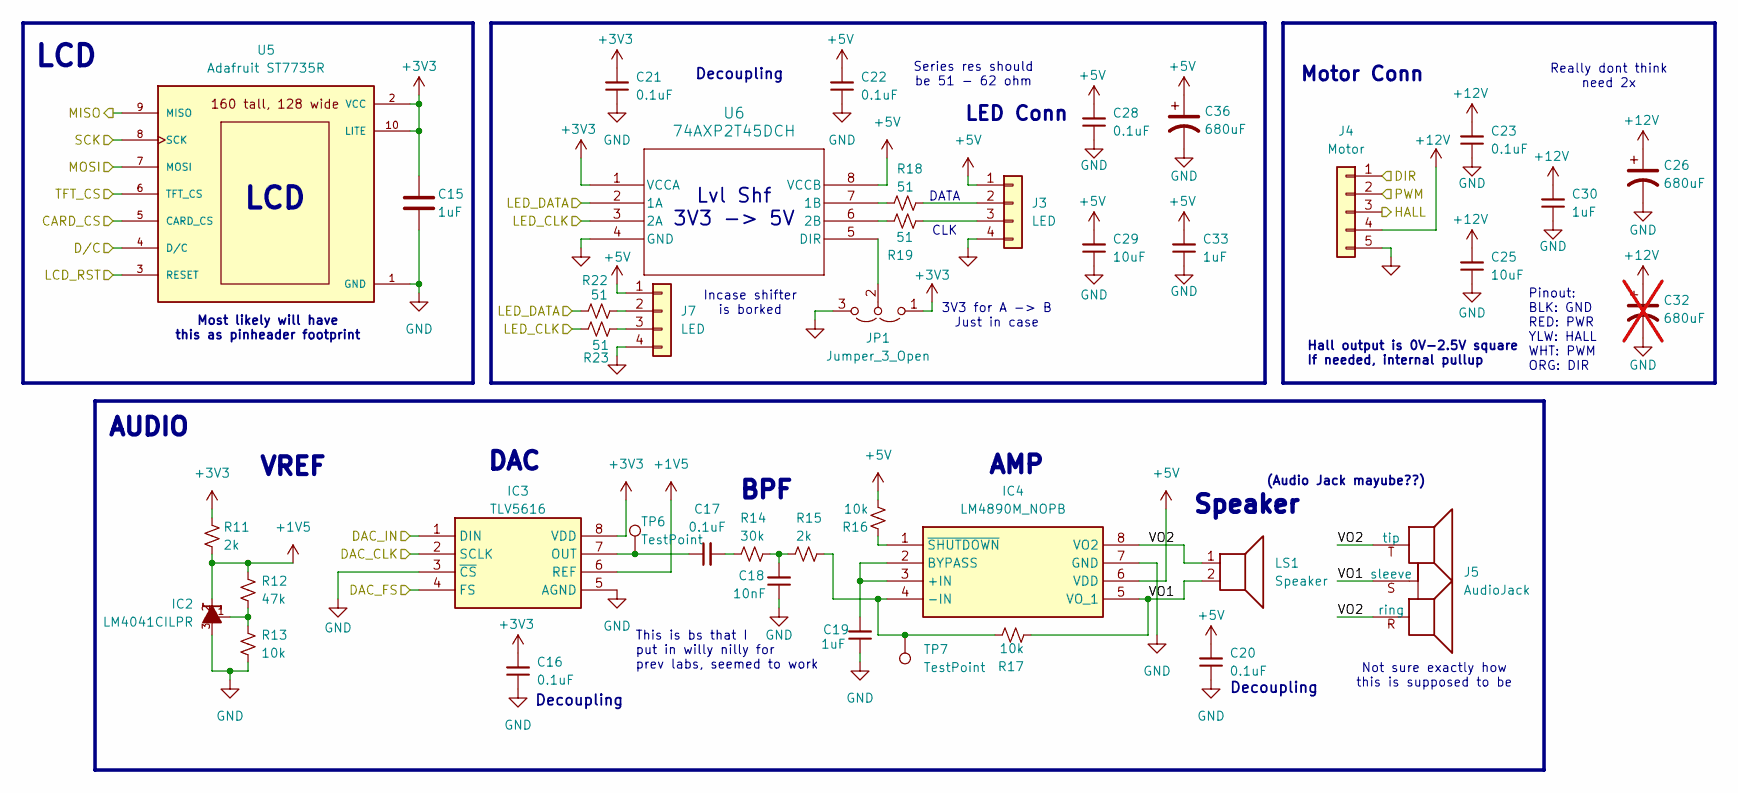
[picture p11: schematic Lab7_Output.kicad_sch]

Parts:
C15, C19, C30, C33: 1uF; C_Axial_200mil
C16, C17, C20, C21, C22, C23, C28: 0.1uF; C_Axial_200mil
C18: 10nF; C_Axial_200mil
C25, C29: 10uF; C_Axial_200mil
C26, C36: 680uF; C_Radial_D10.0mm_H20.0mm_P5.00mm
C32: 680uF; C_Radial_D10.0mm_H20.0mm_P5.00mm; not fitted
IC2: LM4041CILPR; ti_LM4041CILPR
IC3: TLV5616; DIP-8_W7.62mm_LongPads
IC4: LM4890M_NOPB; ti_LM4890M_NOPB; Mouser Part Number 926-LM4890M/NOPB
J3, J7: LED; PinHeader_1x04_P2.54mm_Vertical
J4: Motor; PinHeader_1x05_P2.54mm_Vertical
J5: AudioJack; Jack_3.5mm_CUI_SJ1-3523N_Horizontal
JP1: Jumper_3_Open; PinHeader_1x03_P2.54mm_Vertical
LS1: Speaker; PinHeader_2x01_P2.54mm_Vertical
R11, R15: 2k; R_Axial_DIN0204_L3.6mm_D1.6mm_P7.62mm_Horizontal
R12: 47k; R_Axial_DIN0204_L3.6mm_D1.6mm_P7.62mm_Horizontal
R13, R16, R17: 10k; R_Axial_DIN0204_L3.6mm_D1.6mm_P7.62mm_Horizontal
R14: 30k; R_Axial_DIN0204_L3.6mm_D1.6mm_P7.62mm_Horizontal
R18, R19, R22, R23: 51; R_Axial_DIN0204_L3.6mm_D1.6mm_P7.62mm_Horizontal
TP6, TP7: TestPoint; PinHeader_1x01_P2.54mm_Vertical
U5: Adafruit ST7735R; PinHeader_1x10_P2.54mm_Vertical
U6: 74AXP2T45DCH

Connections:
+1V5: IC2.2, IC3.6 (REF), R11.2, R12.1
+3V3: C15.1, C16.2, C21.2, IC3.8 (VDD), JP1.1 (A), R11.1, U5.2 (VCC), U5.10 (LITE), U6.1 (VCCA); also elsewhere on the board
+5V: C20.2, C22.2, C28.2, C29.2, C33.2, C36.1, IC4.6 (VDD), J3.1, J7.1, R16.2, U6.8 (VCCB); also elsewhere on the board
+12V: C23.2, C25.2, C26.1, C30.2, C32.1, J4.4; also elsewhere on the board
/Lab7_Output/VO1: IC4.5 (VO_1), J5.S (sleeve), LS1.2, R17.1
/Lab7_Output/VO2: IC4.8 (VO2), J5.R (ring), J5.T (tip), LS1.1
/PA2: U5.8 (SCK); also elsewhere on the board
/PA3: U5.6 (TFT_CS); also elsewhere on the board
/PA4: U5.9 (MISO); also elsewhere on the board
/PA5: U5.7 (MOSI); also elsewhere on the board
/PA6: U5.4 (D/C); also elsewhere on the board
/PA7: U5.3 (RESET); also elsewhere on the board
/PB0: U5.5 (CARD_CS); also elsewhere on the board
/PB4: R23.1, U6.3 (2A); also elsewhere on the board
/PB7: R22.2, U6.2 (1A); also elsewhere on the board
/PC4: J4.3; also elsewhere on the board
/PC5: J4.2; also elsewhere on the board
/PC6: J4.1; also elsewhere on the board
/PD0: IC3.2 (SCLK); also elsewhere on the board
/PD1: IC3.4 (FS); also elsewhere on the board
/PD3: IC3.1 (DIN); also elsewhere on the board
GND: C15.2, C16.1, C18.1, C19.1, C20.1, C21.1, C22.1, C23.1, C25.1, C26.2, C28.1, C29.1, C30.1, C32.2, C33.1, C36.2, IC2.3, IC3.3 (~CS), IC3.5 (AGND), IC4.7 (GND), J3.4, J4.5, J7.4, JP1.3 (B), R13.2, U5.1 (GND), U6.4 (GND); also elsewhere on the board
unnamed: C17.2, R14.1
unnamed: C18.2, R14.2, R15.1
unnamed: IC2.1, R12.2, R13.1
unnamed: C17.1, IC3.7 (OUT), TP6.1
unnamed: C19.2, IC4.2 (BYPASS), IC4.3 (+IN)
unnamed: IC4.4 (-IN), R15.2, R17.2, TP7.1
unnamed: IC4.1 (~SHUTDOWN), R16.1
unnamed: J3.2, R18.1
unnamed: J3.3, R19.2
unnamed: J7.2, R22.1
unnamed: J7.3, R23.2
unnamed: JP1.2 (C), U6.5 (DIR)
unnamed: R18.2, U6.7 (1B)
unnamed: R19.1, U6.6 (2B)

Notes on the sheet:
3V3 for A -> B Just in case
Most likely will have this as pinheader footprint
Decoupling
AUDIO
Not sure exactly how this is supposed to be
DAC
BPF
Incase shifter is borked
DATA
AMP
LCD
Speaker
CLK
Really dont think need 2x
This is bs that I put in willy nilly for prev labs, seemed to work
Series res should be 51 - 62 ohm
Motor Conn
Lvl Shf 3V3 -> 5V
VREF
LED Conn
Hall output is 0V-2.5V square If needed, internal pullup
Pinout: BLK: GND RED: PWR YLW: HALL WHT: PWM ORG: DIR
(Audio Jack mayube??)

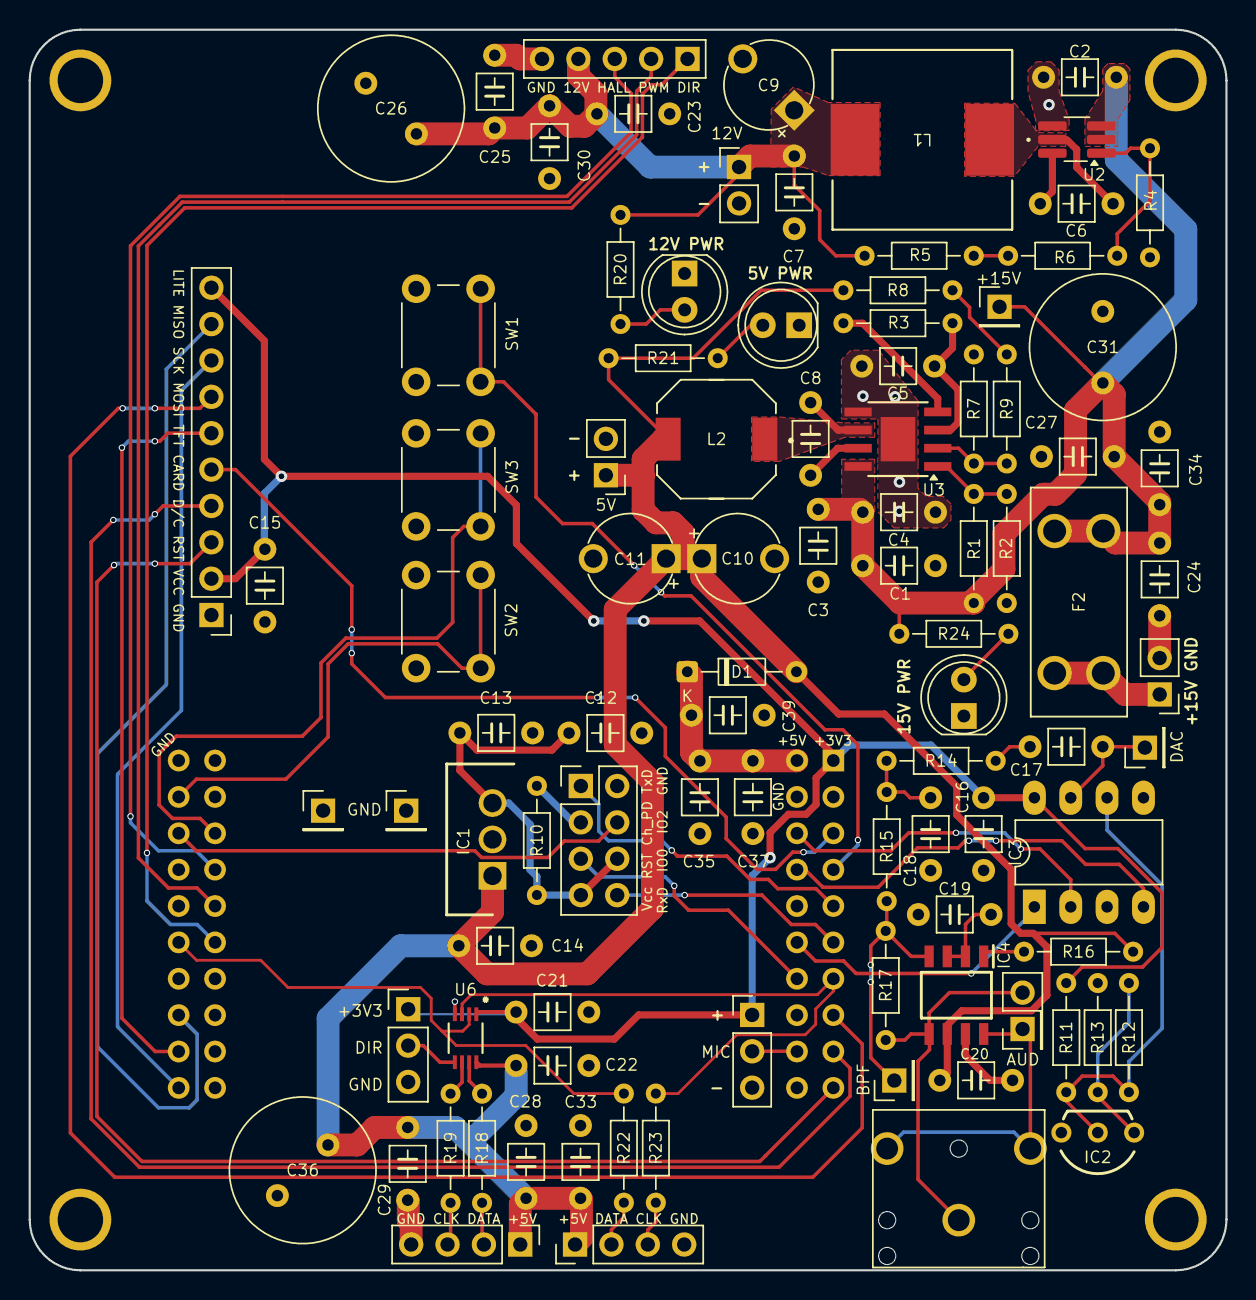
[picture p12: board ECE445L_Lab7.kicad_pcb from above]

Board: 2 copper layers, 83.6 x 86.6 mm, 100 parts (1 on the bottom side), 63 nets.

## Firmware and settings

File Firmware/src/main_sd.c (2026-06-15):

/**
 * @file main_sd.c
 * @brief POV LED globe driver — SD card animation + ROM static image support
 *
 * Drives a 144(-1)-LED SK9822 strip as a persistence-of-vision globe.
 * Supports two display modes:
 *   - 8-bit static images (ROM or SD card, 256-colour palette)
 *   - 4-bit animations   (SD card, 16-colour palette, double-buffered)
 *
 * Column timing is driven by Timer4A, either at a fixed rate or
 * synchronised to motor hall-sensor feedback. Frame data is shifted
 * out via SSI2 + uDMA (ping-pong, channel 13).
 *
 * LCD menu integration: Globe_ToggleMode() and Globe_ChangeContent()
 * are called from LCD.c to switch between content at runtime.
 */

#include <stdint.h>
#include "Drivers/inc/tm4c123gh6pm.h"
#include "Drivers/inc/PLL.h"
#include "Drivers/inc/SK9822_DMA_SSI.h"
#include "Drivers/inc/SysTickInts.h"
#include "Drivers/inc/SK9822.h"
#include "Drivers/inc/Motor.h"
#include "Drivers/inc/GPIO.h"
#include "Drivers/inc/diskio.h"
#include "Drivers/inc/DMA_Common.h"
#include "Drivers/inc/SD_DMA.h"
#include "Drivers/inc/ff.h"
#include "Drivers/inc/LCD.h"
#include "Drivers/inc/ST7735.h"
#include "Drivers/inc/Timer4A.h"
#include "Drivers/inc/Mic.h"
#include "Data/cat_space/cat_space_palette.h"
#include "Data/frog/frog_palette.h"
#include "Data/map_data.h"
#include "Data/map_palette.h"
#include "Data/dermot/dermot_data.h"
#include "Data/dermot/dermot_palette.h"
#include "Data/vote/vote_data.h"
#include "Data/vote/vote_palette.h"
#include "Data/lebron/lebron_data.h"
#include "Data/lebron/lebron_palette.h"
#include "Data/eye/eye_data.h"
#include "Data/eye/eye_palette.h"
#include "Data/baby/baby_palette.h"
#include "Data/boi/boi_palette.h"
#include "main.h"

void DisableInterrupts(void);
void EnableInterrupts(void);
void WaitForInterrupt(void);

static void LoadDMA(void);
static void BuildFrame(void);
static void INITIALIZE(void);
static void SD_LoadFile(const char *filename);
static void SD_LoadNextFrame(void);
static void LEEEED(void);
void Globe_ToggleMode(void);
void Globe_ChangeContent(void);

/* ─────────────────────────────────────────────────────────────────── */
// #define FIXED_TIMER              /* For testing */
#define HALL_SYNC                   /* Period tracks motor hall feedback    */

/*
 * Hall-sync:
 *   colPeriod = revPeriod × MOTOR_GEAR_RATIO / SD_NUM_COLUMNS
 *   140 cols / 6 motor revs per gear rev = ~23.3 cols per motor rev
 */
#define FIXED_PERIOD  152000

/* ─────────────────────────────────────────────────────────────────── */
// #define ISR_BUILD_IN_TIMER       /* LoadDMA + BuildFrame in Timer4A ISR  */
#define ISR_BUILD_ON_DMA_DONE       /* LoadDMA in timer; BuildFrame on DMA done */

/* ─────────────────────────────────────────────────────────────────── */

typedef enum {
    MODE_8BIT_STATIC,       /* Single 8-bit image, loops forever          */
    MODE_4BIT_ANIM,         /* 4-bit animation, double-buffered from SD   */
    MODE_MIC                /* VU meter driven by microphone ADC          */
} DisplayMode_t;

static volatile DisplayMode_t displayMode = MODE_4BIT_ANIM;

/* ── Double buffer (SPI wire format) ────────────────────────────────────── *
 * DMA reads from LIVE while CPU builds the next column into BUFF.
 * Pointers swap after each completed DMA transfer.                         */

static uint8_t  DMA_FRAME[FRAMESIZE];
static uint8_t  BUF_FRAME[FRAMESIZE];
static uint8_t *LIVE = DMA_FRAME;
static uint8_t *BUFF = BUF_FRAME;

extern volatile uint8_t  dmaBusy;
extern volatile uint32_t msTick;

/* ── SD / globe data buffers ────────────────────────────────────────────── *
 * TM4C123 SRAM = 32 KB. Union overlays both layouts on ~20 KB:
 *   8-bit static:  140 × 143 = 20,020 B (one buffer, no animation)
 *   4-bit anim:  2 × 140 × 72 = 20,160 B (double-buffered)               */

#define SD_NUM_COLUMNS  140
#define SD_NUM_LEDS     143 // cuz one of them fkn broke bruh
#define SD_PACKED_COL   ((SD_NUM_LEDS + 1) / 2)  /* 72 bytes per 4-bit column */

static union {  // For being able to store 8bit & 4bit in RAM
    uint8_t static8[SD_NUM_COLUMNS][SD_NUM_LEDS];
    struct {
        uint8_t a[SD_NUM_COLUMNS][SD_PACKED_COL];
        uint8_t b[SD_NUM_COLUMNS][SD_PACKED_COL];
    } anim4;
} sdMem;

static uint8_t (*sdActive)[SD_PACKED_COL]  = sdMem.anim4.a;
static uint8_t (*sdLoading)[SD_PACKED_COL] = sdMem.anim4.b;

static uint16_t        numColumns      = SD_NUM_COLUMNS;
static uint16_t        totalFrames     = 0;
static uint16_t        currentFrameIdx = 0;
static volatile uint8_t sdReady        = 0;  /* 1 = sdLoading buffer complete */

static FATFS  g_sFatFs;
static FIL    g_File;

static const uint8_t (*activePalette)[3] = cat_space_palette;

extern volatile MotorRampState_t motorRampState;
extern volatile uint8_t motor_state_changed;

static uint8_t  frameDirty   = 0;
static uint8_t  framePending = 1;
static uint16_t col          = 0;
static uint8_t  brightness   = 16;  /* 0–31 (31 is ALOT) */

/* ─────────────────────────────────────────────────────────────────── */

typedef enum { SRC_ROM, SRC_SD } DataSource_t;

static volatile DataSource_t dataSource = SRC_SD;
static const uint8_t (*romData)[NUM_LEDS] = ((void *)0);
static uint16_t romNumColumns = 0;

/* ─────────────────────────────────────────────────────────────────── */

/** Load 8-bit static image from SD into sdMem.static8 */
void SetMode_8bit(const char *filename, const uint8_t palette[][3]) {
    DisableInterrupts();
    displayMode   = MODE_8BIT_STATIC;
    dataSource    = SRC_SD;
    activePalette = palette;
    col = 0; frameDirty = 0; framePending = 1; sdReady = 0;
    EnableInterrupts();
    SD_LoadFile(filename);
}

/** Load 4-bit animation from SD, double-buffered */
void SetMode_4bit(const char *filename, const uint8_t palette[][3]) {
    DisableInterrupts();
    displayMode   = MODE_4BIT_ANIM;
    dataSource    = SRC_SD;
    activePalette = palette;
    sdActive  = sdMem.anim4.a;
    sdLoading = sdMem.anim4.b;
    col = 0; frameDirty = 0; framePending = 1; sdReady = 0;
    EnableInterrupts();
    SD_LoadFile(filename);
}

/** Display a ROM8-bit image */
void SetMode_ROM(const uint8_t data[][NUM_LEDS], const uint8_t palette[][3], uint16_t cols) {
    DisableInterrupts();
    displayMode   = MODE_8BIT_STATIC;
    dataSource    = SRC_ROM;
    activePalette = palette;
    romData       = data;
    romNumColumns = cols;
    numColumns    = cols;
    col = 0; frameDirty = 0; framePending = 1; sdReady = 0;
    EnableInterrupts();
}

/** Switch to mic mode (Yell into mic to light up globe mode) */
void SetMode_Mic(void) {
    DisableInterrupts();
    displayMode  = MODE_MIC;
    col = 0; frameDirty = 0; framePending = 1; sdReady = 0;
    EnableInterrupts();
}

/* ── Content table ──────────────────────────────────────────────────────── *
 * LCD "Mode" button toggles picture <-> animation.
 * LCD "Change" button cycles within the current category.                  */

// Potentially adding 1-bit mode for long form videos (Bad Apple??)
typedef enum {
    CONTENT_ROM_8BIT,
    CONTENT_SD_8BIT,
    CONTENT_SD_4BIT_ANIM
} ContentType_t;

typedef struct {
    const char       *name;
    ContentType_t     type;
    const uint8_t   (*romData)[NUM_LEDS];   /* ROM images only  */
    const uint8_t   (*palette)[3];
    uint16_t          romCols;              /* ROM images only  */
    const char       *sdFilename;           /* SD images only   */
} ContentEntry_t;

/*
 * When adding stuff into /Data folder, add in here to be able to switch to it
 */
static const ContentEntry_t pictures[] = {
    { "Earth",  CONTENT_ROM_8BIT, map_data,    map_palette,    GLOBE_NUM_COLUMNS, ((void *)0) },
    { "Dermot", CONTENT_ROM_8BIT, dermot_data, dermot_palette, GLOBE_NUM_COLUMNS, ((void *)0) },
    { "Vote",   CONTENT_ROM_8BIT, vote_data,   vote_palette,   GLOBE_NUM_COLUMNS, ((void *)0) },
    { "eye",    CONTENT_ROM_8BIT, eye_data,    eye_palette,    GLOBE_NUM_COLUMNS, ((void *)0) },
};
#define NUM_PICTURES (sizeof(pictures) / sizeof(pictures[0]))

/*
 * When adding stuff into SD card, add in here to be able to switch to it
 */
static const ContentEntry_t animations[] = {
    { "Cat",       CONTENT_SD_4BIT_ANIM, ((void *)0), cat_space_palette, 0, "cat.bin" },
    { "Frog",      CONTENT_SD_4BIT_ANIM, ((void *)0), frog_palette,      0, "fro.bin" },
    { "baby",      CONTENT_SD_4BIT_ANIM, ((void *)0), baby_palette,      0, "bby.bin" },
    { "boi",       CONTENT_SD_4BIT_ANIM, ((void *)0), boi_palette,       0, "boi.bin" },
};
#define NUM_ANIMATIONS (sizeof(animations) / sizeof(animations[0]))

static uint8_t pictureIdx   = 0;
static uint8_t animationIdx = 0;

static void Content_Load(const ContentEntry_t *e) {
    switch (e->type) {
        case CONTENT_ROM_8BIT:     SetMode_ROM(e->romData, e->palette, e->romCols); break;
        case CONTENT_SD_8BIT:      SetMode_8bit(e->sdFilename, e->palette);         break;
        case CONTENT_SD_4BIT_ANIM: SetMode_4bit(e->sdFilename, e->palette);         break;
    }
}

/** Cycle display mode: picture -> animation -> mic -> picture.  */
void Globe_ToggleMode(void) {
    extern volatile uint8_t ledModeAnim;

    if (displayMode == MODE_MIC) {
        ledModeAnim = 0;
        Content_Load(&pictures[pictureIdx]);
    } else if (!ledModeAnim) {
        ledModeAnim = 1;
        Content_Load(&animations[animationIdx]);
    } else {
        ledModeAnim = 2;
        SetMode_Mic();
    }
}

/** Cycle to next entry in category. */
void Globe_ChangeContent(void) {
    extern volatile uint8_t ledModeAnim;
    if (ledModeAnim) {
        animationIdx = (animationIdx + 1) % NUM_ANIMATIONS;
        Content_Load(&animations[animationIdx]);
    } else {
        pictureIdx = (pictureIdx + 1) % NUM_PICTURES;
        Content_Load(&pictures[pictureIdx]);
    }
}

/* ─────────────────────────────────────────────────────────────────── */

/** Swap buffers if a new frame is ready, then start DMA. */
static void LoadDMA(void) {
    if (!dmaBusy) {
        if (frameDirty) {
            uint8_t *tmp = LIVE; LIVE = BUFF; BUFF = tmp;
            frameDirty = 0;
            framePending = 1;
        }
        SK9822_DMA_Start(LIVE, FRAMESIZE);
    }
}

volatile uint16_t raw;

/** Build the next column into BUFF from the active data source. */
static void BuildFrame(void) {
    if (!framePending) return;

    if (displayMode == MODE_MIC) {
        raw = Mic_Read();
        uint16_t level = ((raw * FRONT_LEDS) / 4096) - 33;     /* scale to LED */
        BuildFrame_VU(BUFF, level, brightness);
    } else if (displayMode == MODE_8BIT_STATIC) {
        if (dataSource == SRC_ROM && romData != ((void *)0))
             BuildFrame_8bit(BUFF, romData[col], activePalette, brightness);
        else BuildFrame_8bit(BUFF, sdMem.static8[col], activePalette, brightness);
    } else   BuildFrame_4bit(BUFF, sdActive[col], activePalette, brightness);

    col = (col + 1) % numColumns;

    /* Swap animation buffers at rotation boundary */
    if (displayMode == MODE_4BIT_ANIM && col == 0 && sdReady) {
        uint8_t (*tmp)[SD_PACKED_COL] = sdActive;
        sdActive = sdLoading; sdLoading = tmp;
        sdReady = 0;
    }
    frameDirty = 1;
}

/* ─────────────────────────────────────────────────────────────────── */

#ifdef HALL_SYNC
static void HallSync_UpdatePeriod(void) {
    uint32_t rev = Motor_GetRevPeriod();
    if (rev > 0) {
        uint32_t p = (rev * MOTOR_GEAR_RATIO) / SD_NUM_COLUMNS;
        if (p < 5000)   p = 5000;    /* clamp: ~16 kHz max  */
        if (p > 400000) p = 400000;  /* clamp: ~200 Hz min  */
        Timer4A_SetPeriod(p);
    }
}
#endif

#ifdef ISR_BUILD_IN_TIMER

static void LEEEED(void) {
#ifdef HALL_SYNC
    HallSync_UpdatePeriod();
#endif
    LoadDMA();
    BuildFrame();
}

#endif /* ISR_BUILD_IN_TIMER */

#ifdef ISR_BUILD_ON_DMA_DONE

void DMA_Done_Callback(void) { BuildFrame(); }

static void LEEEED(void) {
#ifdef HALL_SYNC
    HallSync_UpdatePeriod();
#endif
    LoadDMA();
}

#endif /* ISR_BUILD_ON_DMA_DONE */

/* ─────────────────────────────────────────────────────────────────── */

int main(void) {
    DisableInterrupts();
    INITIALIZE();
    EnableInterrupts();

    SetMode_ROM(map_data, map_palette, GLOBE_NUM_COLUMNS);
    Timer4A_Init(LEEEED, FIXED_PERIOD, 3);  /* starting period until hall-sync locks */

    while (1) {
        if (displayMode == MODE_4BIT_ANIM && !sdReady) SD_LoadNextFrame();

        buttonHandler();    // mmm butts

        if (motor_state_changed) {          // Always display motor status
            switch (motorRampState) {
                case MOTOR_IDLE:          ST7735_DrawString2(22, 4, "~", ST7735_YELLOW, 3); break;
                case MOTOR_SPINNING_UP:   ST7735_DrawString2(22, 4, "+", ST7735_GREEN, 3);  break;
                case MOTOR_SPINNING_DOWN: ST7735_DrawString2(22, 4, "-", ST7735_RED, 3);    break;
            }
            motor_state_changed = 0;
        }
    }
}

/* ─────────────────────────────────────────────────────────────────── */

/**
 * Mount SD, open file, load first frame.
 * 8-bit: reads full frame into sdMem.static8, closes file.
 * 4-bit: reads first frame into sdLoading, keeps file open for streaming.
 *
 * SD card bs, most driver code given by Valvanoware.
 */
static void SD_LoadFile(const char *filename) {
    FRESULT fr;
    UINT    br;

    fr = f_mount(&g_sFatFs, "", 0);
    if (fr != FR_OK) { while (1) {} }

    fr = f_open(&g_File, filename, FA_READ);
    if (fr != FR_OK) { while (1) {} }

    if (displayMode == MODE_8BIT_STATIC) {
        uint32_t frameBytes = (uint32_t)SD_NUM_COLUMNS * SD_NUM_LEDS;
        fr = f_read(&g_File, sdMem.static8, frameBytes, &br);
        if (fr != FR_OK || br < SD_NUM_LEDS) { while (1) {} }
        numColumns  = (uint16_t)(br / SD_NUM_LEDS);
        totalFrames = 1;
        f_close(&g_File);
    } else {
        uint32_t frameBytes = (uint32_t)SD_NUM_COLUMNS * SD_PACKED_COL;
        DWORD fileSize = f_size(&g_File);
        totalFrames = (uint16_t)(fileSize / frameBytes);
        if (totalFrames == 0) { while (1) {} }
        fr = f_read(&g_File, sdLoading, frameBytes, &br);
        if (fr != FR_OK || br < SD_PACKED_COL) { while (1) {} }
        numColumns      = (uint16_t)(br / SD_PACKED_COL);
        currentFrameIdx = 0;
        sdReady         = 1;
    }
}

/** Read next animation frame into sdLoading. Wraps at end of file. */
static void SD_LoadNextFrame(void) {
    FRESULT fr;
    UINT    br;
    uint32_t frameBytes = (uint32_t)SD_NUM_COLUMNS * SD_PACKED_COL;

    currentFrameIdx = (currentFrameIdx + 1) % totalFrames;
    if (currentFrameIdx == 0) f_lseek(&g_File, 0);

    fr = f_read(&g_File, sdLoading, frameBytes, &br);
    if (fr != FR_OK || br < SD_PACKED_COL) { while (1) {} }

    numColumns = (uint16_t)(br / SD_PACKED_COL);
    sdReady = 1;
}

/* ─────────────────────────────────────────────────────────────────── */

static void INITIALIZE(void) {
    PLL_Init(Bus80MHz);
    SK9822_20MHZ();
    DMA_Init();
    SK9822_DMA_CH13_Init();
    SD_DMA_CH10_Init();
    Motor_Init();
    Motor_Stop();
    PF_Init();
    PB_Init();
    SysTick_Init(80000);    /* 1 ms tick */
    Mic_Init();
    BuildFrame_Solid(LIVE, 0, 0, 0, 0);
    BuildFrame_Solid(BUFF, 0, 0, 0, 0);
    LCD_Menu_Init();
}

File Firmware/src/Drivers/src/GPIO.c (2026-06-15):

/**
 * @file GPIO.c
 * @brief Port F (motor buttons) and Port B (LCD buttons) GPIO driver.
 *
 * Port F:
 *   PF0 — motor spinup  (falling edge, pull-up)
 *   PF4 — motor spindown (falling edge, pull-up)
 *   PF1-3 — RGB LEDs (heartbeat)
 *
 * Port B:
 *   PB1 — LCD Up
 *   PB2 — LCD Down
 *   PB3 — LCD Select
 */

#include <stdint.h>
#include "../inc/tm4c123gh6pm.h"
#include "../inc/Motor.h"

#define LEDS      (*((volatile uint32_t *)0x40025038))
#define RED       0x02
#define BLUE      0x04
#define GREEN     0x08

#define PortF   0x20
#define PortB   0x02

#define UNLOCK  0x4C4F434B
#define PF4_0   0x1F
#define PU      0x11
#define IN_OUT  0x0E
#define PF4     (1 << 4)
#define PF0     (1)

#define DEBOUNCE_MS     100
#define DEBOUNCE_MS_LCD 150

// For fancy HBT :P
static const int32_t COLORWHEEL[7] = { RED, RED+GREEN, GREEN, GREEN+BLUE, BLUE, BLUE+RED, RED+GREEN+BLUE };

extern uint32_t msTick;
extern volatile uint32_t lcd_last_press;

void Menu_Up(void);
void Menu_Down(void);
void Menu_Select(void);

void LED_Init(void) {
    volatile uint32_t delay;
    SYSCTL_RCGCGPIO_R |= SYSCTL_RCGC2_GPIOF;
    (void)delay;
    GPIO_PORTF_DIR_R   = 0x0E;
    GPIO_PORTF_AFSEL_R &= ~0x0E;
    GPIO_PORTF_DEN_R   |= 0x0E;
    GPIO_PORTF_PCTL_R  = 0;
    GPIO_PORTF_AMSEL_R = 0;
    LEDS = 0;
}

void PF_Init(void) {
    SYSCTL_RCGCGPIO_R |= PortF;
    while ((SYSCTL_PRGPIO_R & PortF) == 0) {}
    GPIO_PORTF_LOCK_R  = UNLOCK;
    GPIO_PORTF_CR_R    = PF4_0;
    GPIO_PORTF_DIR_R   = IN_OUT;
    GPIO_PORTF_DR2R_R  = 0x0E;
    GPIO_PORTF_PUR_R   = PU;
    GPIO_PORTF_DEN_R   = PF4_0;
    GPIO_PORTF_DATA_R  = 0x0E;

    GPIO_PORTF_IS_R  &= ~(PF4 | PF0);
    GPIO_PORTF_IBE_R &= ~(PF4 | PF0);
    GPIO_PORTF_IEV_R &= ~(PF4 | PF0);
    GPIO_PORTF_ICR_R  =  (PF4 | PF0);
    GPIO_PORTF_IM_R  |=  (PF4 | PF0);

    NVIC_PRI7_R  = (NVIC_PRI7_R & 0x00FFFFFF) | 0xA0000000; /* pri 5 */
    NVIC_EN0_R  |= (1 << 30);
    LEDS = 0;
}

static uint8_t idx = 0;

void LED_HBT(void) {        // cycle
    LEDS = COLORWHEEL[idx];
    idx = (idx + 1) % 7;
}

uint8_t PF_In(void) {
    uint32_t data = ~GPIO_PORTF_DATA_R;
    return (uint8_t)(((data & 0x10) >> 3) | (data & 0x01));
}

volatile uint32_t last_press = 0;
volatile uint8_t  PF4_High   = 0;
volatile uint8_t  PF0_High   = 0;

void GPIOPortF_Handler(void) {
    GPIO_PORTF_ICR_R = PF4_0;
    if ((msTick - last_press) < DEBOUNCE_MS) return;
    last_press = msTick;

    uint8_t sw = PF_In();
    if (sw & 0x01) { PF0_High = 1; Motor_Spinup(MOTOR_SPINUP_MS, MOTOR_SETPOINT); }
    if (sw & 0x02) { PF4_High = 1; Motor_Spindown(MOTOR_SPINDOWN_MS); }
}

void PB_Init(void) {
    SYSCTL_RCGCGPIO_R |= PortB;
    while ((SYSCTL_PRGPIO_R & PortB) == 0) {}

    GPIO_PORTB_DIR_R   &= ~0x0E;
    GPIO_PORTB_AFSEL_R &= ~0x0E;
    GPIO_PORTB_DEN_R   |=  0x0E;
    GPIO_PORTB_PCTL_R  &= ~0x0000FFF0;
    GPIO_PORTB_AMSEL_R  =  0;
    GPIO_PORTB_PUR_R   |=  0x0E;

    GPIO_PORTB_IS_R  &= ~0x0E;
    GPIO_PORTB_IBE_R &= ~0x0E;
    GPIO_PORTB_IEV_R &= ~0x0E;
    GPIO_PORTB_ICR_R  =  0x0E;
    GPIO_PORTB_IM_R  |=  0x0E;

    NVIC_EN0_R  |= (1 << 1);
    NVIC_PRI0_R  = (NVIC_PRI0_R & 0xFFFF00FF) | 0x0000A000; /* pri 5 */
}

uint8_t PB_In(void) { return (~GPIO_PORTB_DATA_R & 0x0E); }

void GPIOPortB_Handler(void) {
    GPIO_PORTB_ICR_R = 0x0E;
    if ((msTick - lcd_last_press) < DEBOUNCE_MS_LCD) return;
    lcd_last_press = msTick;

    uint8_t pb = ~GPIO_PORTB_DATA_R & 0x0E;
    if (pb & 0x02) Menu_Up();
    if (pb & 0x04) Menu_Down();
    if (pb & 0x08) Menu_Select();
}

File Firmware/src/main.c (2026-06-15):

/**
 * @file main.c
 * @brief POV LED globe driver — ROM-only static images (no SD card)
 *
 * Drives a 143-LED SK9822 strip as a persistence-of-vision globe
 * using image data baked into flash. Column timing via Timer4A,
 * frame data shifted out via SSI2 + uDMA (ping-pong, channel 13).
 */

#include <stdint.h>
#include "../inc/tm4c123gh6pm.h"
#include "Drivers/inc/PLL.h"
#include "Drivers/inc/SK9822_DMA_SSI.h"
#include "Drivers/inc/SysTickInts.h"
#include "Drivers/inc/SK9822.h"
#include "Drivers/inc/Motor.h"
#include "Drivers/inc/GPIO.h"
#include "Drivers/inc/LCD.h"
#include "Data/map_data.h"
#include "Data/map_palette.h"
#include "Drivers/inc/Timer4A.h"

#include "Data/globe_old/globe_data.h"
#include "Data/globe_old/palette.h"

#include "Drivers/inc/ST7735.h"
#include "main.h"

void DisableInterrupts(void);
void EnableInterrupts(void);
void WaitForInterrupt(void);

static void INITIALIZE(void);
static void LoadDMA(uint8_t *frameDirty, uint8_t *framePending);
static void BuildFrame(uint8_t *frameDirty, uint8_t framePending, uint16_t *col, uint8_t brt);

/* ── Column timing mode (uncomment one) ─────────────────────────────────── */
// #define FIXED_TIMER              /* Constant Timer4A period              */
#define HALL_SYNC                   /* Period tracks motor hall feedback    */

/*
 * FIXED_PERIOD: Timer4A reload value (80 MHz ticks).
 *   152000 → ~526 Hz  (42% duty, ~3.8 rev/s, 140 cols)
 *    76000 → ~1053 Hz (2× motor speed)
 *
 * Hall-sync formula:
 *   colPeriod = revPeriod × MOTOR_GEAR_RATIO / GLOBE_NUM_COLUMNS
 *   140 cols / 6 motor revs per gear rev ≈ 23.3 cols per motor rev
 */
#define FIXED_PERIOD       152000
#define COLS_PER_MOTOR_REV (GLOBE_NUM_COLUMNS / MOTOR_GEAR_RATIO)

/* ── ISR structure (uncomment one) ──────────────────────────────────────── */
// #define ISR_BUILD_IN_TIMER       /* LoadDMA + BuildFrame in Timer4A ISR  */
#define ISR_BUILD_ON_DMA_DONE       /* LoadDMA in timer; BuildFrame on DMA done */

/*
 * ISR_BUILD_IN_TIMER:
 *   Simple. Both functions run in one ISR (~10 µs). Fine up to ~50 kHz.
 *
 * ISR_BUILD_ON_DMA_DONE:
 *   Timer ISR only kicks DMA (~2 µs). BuildFrame runs in SSI2_Handler
 *   after the 592-byte SPI transfer completes (~30 µs at 20 MHz).
 *   Requires DMA_Done_Callback() hook in SK9822_DMA_SSI.c.
 */

/* ── Double buffer ──────────────────────────────────────────────────────── *
 * DMA reads from LIVE while CPU builds the next column into BUFF.
 * Pointers swap after each completed DMA transfer.                         */

static uint8_t  DMA_FRAME[FRAMESIZE];
static uint8_t  BUF_FRAME[FRAMESIZE];
static uint8_t *LIVE = DMA_FRAME;
static uint8_t *BUFF = BUF_FRAME;

extern volatile uint8_t dmaBusy;
extern volatile uint32_t msTick;
extern volatile MotorRampState_t motorRampState;
extern volatile uint8_t motor_state_changed;

static uint8_t  frameDirty   = 0;
static uint8_t  framePending = 1;
static uint16_t col          = 0;
static uint8_t  brightness   = 8;  /* 0–31 */

/* ── Frame pipeline ─────────────────────────────────────────────────────── */

static void LoadDMA(uint8_t *frameDirty, uint8_t *framePending) {
    if (!dmaBusy) {
        if (*frameDirty) {
            uint8_t *tmp = LIVE; LIVE = BUFF; BUFF = tmp;
            *frameDirty  = 0;
            *framePending = 1;
        }
        SK9822_DMA_Start(LIVE, FRAMESIZE);
    }
}

static void BuildFrame(uint8_t *frameDirty, uint8_t framePending, uint16_t *col, uint8_t brt) {
    if (framePending) {
        BuildFrame_8bit(BUFF, map_data[*col], map_palette, brt);
        //BuildFrame_8bit(BUFF, globe[*col], palette, brt);
        //BuildFrame_8bit(BUFF, dot[*col], dot_palette, brt);
        *col = (*col + 1) % GLOBE_NUM_COLUMNS;
        *frameDirty = 1;
    }
}

/* ── Timer4A ISR ────────────────────────────────────────────────────────── */

#ifdef HALL_SYNC
static void HallSync_UpdatePeriod(void) {
    uint32_t rev = Motor_GetRevPeriod();
    if (rev > 0) {
        uint32_t p = (rev * MOTOR_GEAR_RATIO) / GLOBE_NUM_COLUMNS;
        if (p < 5000)   p = 5000;
        if (p > 400000) p = 400000;
        Timer4A_SetPeriod(p);
    }
}
#endif

#ifdef ISR_BUILD_IN_TIMER

static void LEEEED(void) {
#ifdef HALL_SYNC
    HallSync_UpdatePeriod();
#endif
    LoadDMA(&frameDirty, &framePending);
    BuildFrame(&frameDirty, framePending, &col, brightness);
}

#endif /* ISR_BUILD_IN_TIMER */

#ifdef ISR_BUILD_ON_DMA_DONE

void DMA_Done_Callback(void) {
    BuildFrame(&frameDirty, framePending, &col, brightness);
}

static void LEEEED(void) {
#ifdef HALL_SYNC
    HallSync_UpdatePeriod();
#endif
    LoadDMA(&frameDirty, &framePending);
}

#endif /* ISR_BUILD_ON_DMA_DONE */

/* ── Main ───────────────────────────────────────────────────────────────── */

int main01(void) {
    DisableInterrupts();
    INITIALIZE();
    EnableInterrupts();

    while (1) {
        buttonHandler();
        if (motor_state_changed) {
            switch (motorRampState) {
                case MOTOR_IDLE:          ST7735_DrawString2(22, 4, "~", ST7735_YELLOW, 3); break;
                case MOTOR_SPINNING_UP:   ST7735_DrawString2(22, 4, "+", ST7735_GREEN, 3);  break;
                case MOTOR_SPINNING_DOWN: ST7735_DrawString2(22, 4, "-", ST7735_RED, 3);    break;
            }
            motor_state_changed = 0;
        }
    }
}

/* ── Hardware init ──────────────────────────────────────────────────────── */

static void INITIALIZE(void) {
    PLL_Init(Bus80MHz);
    SK9822_20MHZ();
    DMA_Init();
    SK9822_DMA_CH13_Init();
    Motor_Init();
    Motor_Stop();
    PF_Init();
    PB_Init();
    SysTick_Init(80000);                       /* 1 ms tick */
    BuildFrame_Solid(LIVE, 0, 0, 0, 0);
    BuildFrame_Solid(BUFF, 0, 0, 0, 0);
    Timer4A_Init(LEEEED, FIXED_PERIOD, 3);     /* fallback period until hall-sync locks */
    LCD_Menu_Init();
}

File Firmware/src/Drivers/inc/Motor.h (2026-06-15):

/**
 * @file Motor.h
 * @brief TEC3650 brushless motor driver — PWM speed, direction, hall RPM
 *
 * Pin assignments (Port C):
 *   PC5 — M0PWM7  : PWM speed output, active-low, 20kHz
 *   PC4 — GPIO in : Hall effect feedback, falling-edge interrupt
 *   PC6 — GPIO out: Direction control (0 = forward, 1 = reverse)
 *
 * Active-low PWM.
 */

#ifndef MOTOR_H
#define MOTOR_H

#include <stdint.h>

/* ─────────────────────────────────────────────────────────────────── */

typedef enum {
    MOTOR_IDLE = 0,
    MOTOR_SPINNING_UP,
    MOTOR_SPINNING_DOWN
} MotorRampState_t;

#define MOTOR_SPINDOWN_MS 100   // 100ms/1%
#define MOTOR_SPINUP_MS   250   // 250ms/1%
#define MOTOR_SETPOINT    67    // duty%
#define MIN_STARTSPEED    20    // to overcome friction
#define MAX_SPEED         90    // Safeguard

#define MOTOR_PWM_HZ        20000U
#define MOTOR_PWM_LOAD      (80000000U / MOTOR_PWM_HZ)

/** TEC3650: 4 pole pairs = 12 hall pulses/rev */
#define MOTOR_HALL_PPR      12

/* ── RPM formula constants ──────────────────────────────────────────────────
 * RPM_SCALE  = (SYS_CLK * 60) / MOTOR_HALL_PPR = (80e6 * 60) / 6
 * STALL_DELTA = 1 second at 80 MHz
 * --------------------------------------------------------------------------- */
#define RPM_SCALE     800000000UL
#define RPM_SCALE_REV 4800000000ULL
#define STALL_DELTA   8000000UL

/* ─────────────────────────────────────────────────────────────────── */

#define PORTC_CLK           0x04
#define PWM0_CLK            0x01
#define WT0_CLK             0x01

#define PC4_HALL            0x10    ///< PC4 — hall input
#define PC5_PWM             0x20    ///< PC5 — PWM output
#define PC6_DIR             0x40    ///< PC6 — direction output
#define PC6_DIR_BIT     (*((volatile uint32_t *)(0x40006000 + (PC6_DIR << 2))))

#define PC5_PCTL_SET        0x00400000  ///< PC5 PMC = 4 (M0PWM7)
#define PC5_PCTL_CLR        0x00F00000

/* NVIC — GPIO Port C = IRQ 4 */
#define PORTC_IRQ_EN        (1 << 2)
#define PORTC_IRQ_PRI_MASK  (7U << 21)
#define PORTC_IRQ_PRI2      (2 << 21)

#define MOTOR_FORWARD   0
#define MOTOR_REVERSE   1

/* ─────────────────────────────────────────────────────────────────── */

/**
 * @brief Initialise PWM, GPIO direction, and hall interrupt.
 *
 * PC5 -> M0PWM7 at 20kHz, output held high (motor off).
 * PC6 -> output low (forward).
 * PC4 -> input with pull-up, falling-edge interrupt.
 */
void Motor_Init(void);

/**
 * @brief Set motor speed as a duty cycle percentage.
 *
 * <= 0   -> output permanently high (motor off)
 * >= 100 -> output permanently low  (full speed)
 * 1–99   -> active-low PWM, pulse width scales with percent
 *
 * @param percent  Target speed 0–100.
 * @return         1 on success, 0 ielse.
 */
uint8_t Motor_SetSpeed(int8_t percent);

/**
 * @brief Set motor direction via PC6.
 *
 * Rejected if motor is not fully stopped (currentSpeed > 0)
 *
 * @param dir   MOTOR_FORWARD or MOTOR_REVERSE.
 * @return      1 on success, 0 else
 */
uint8_t Motor_SetDirection(uint8_t dir);

/** @brief Stop motor. */
uint8_t Motor_Stop(void);

/**
 * @brief Return most recently computed RPM.
 *
 * Updated in GPIOPortC_Handler every MOTOR_HALL_PPR pulses (one revolution).
 * Returns last known value.
 */
uint32_t Motor_GetRPM(void);

/** @brief Returns set Duty cycle % */
uint8_t Motor_GetDuty(void);

/** @brief Spins down motor gracefully */
void Motor_Spindown(uint32_t msDelay);

/** @brief RSpins up motor to set point */
void Motor_Spinup(uint32_t msDelay, uint8_t setSpeed);

/** @brief ISR tick */
void Motor_Tick(void);

/** @brief checks for stall */
void Motor_StallCheck(void);

/** @brief Returns gear rpm (globe rpm) */
uint32_t Motor_GetGearRPM(void);

/* ---------------------------------------------------------------------------
 * Hall-sync: locks col timing to hall pulses
 *
 * Hall ISR tracks gear position (0 to GEAR_PPR-1).
 * Motor_GetGearPulseCount() returns the current position within one
 * full gear revolution. Motor_GetRevPeriod() returns the most recent
 * full motor-revolution period in 80 MHz timer counts (sum of
 * MOTOR_HALL_PPR inter-pulse intervals). Returns 0 if no complete
 * revolution has been measured yet.
 * --------------------------------------------------------------------------- */

/** @brief Current gear pulse position [0, GEAR_PPR). */
uint8_t  Motor_GetGearPulseCount(void);

/** @brief Gear angle in degrees [0, 360). */
uint16_t Motor_GetGearAngle(void);

/** @brief Last measured motor revolution period in 80 MHz counts. 0 = unknown. */
uint32_t Motor_GetRevPeriod(void);

/** @brief Gear ratio — motor revs per gear rev */
#define MOTOR_GEAR_RATIO  6

#endif /* MOTOR_H */
